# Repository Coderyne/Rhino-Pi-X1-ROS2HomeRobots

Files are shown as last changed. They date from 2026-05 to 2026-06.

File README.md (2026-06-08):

<div align="center">

# 基于犀牛派X1的家庭机器人







基于犀牛派X1的家庭机器人，集成了视觉、语音、运动控制、SLAM导航和智能家居联动等多种功能，能够实现智能交互和自主导航。

</div>

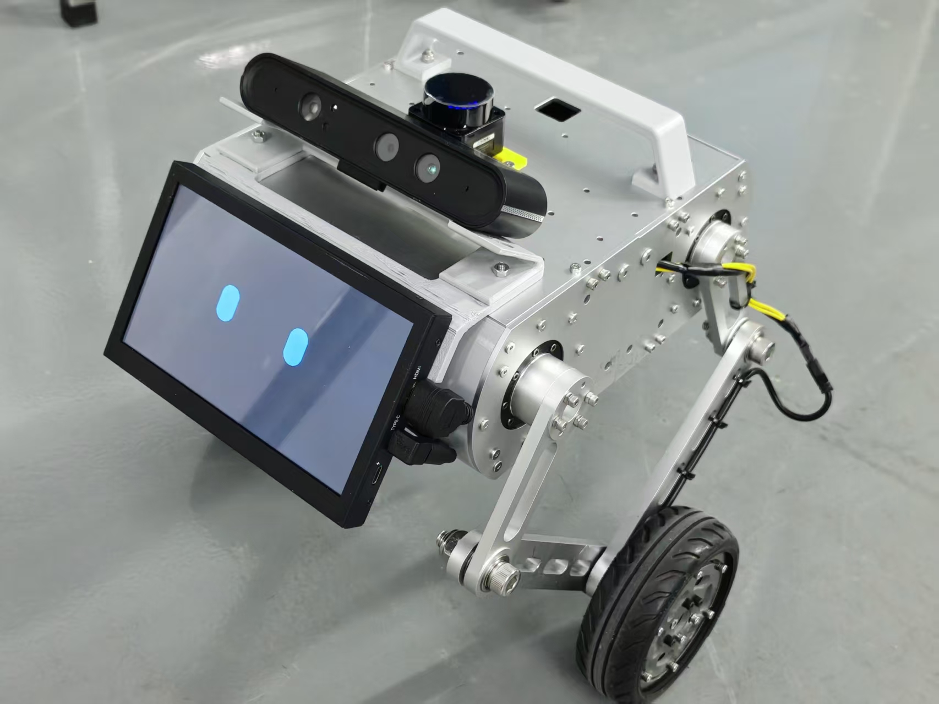
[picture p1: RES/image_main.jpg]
机器人实物图


---

## 目录

- [功能概览](#功能概览)
- [硬件规格](#硬件规格)
- [软件架构](#软件架构)
- [文件结构](#文件结构)
- [安装教程](#安装教程)
- [参考](#参考)
---

## 功能概览

- **轮足机器人控制** — 基于 STM32H723 + FreeRTOS 的底层控制，集成 EKF/Mahony 姿态解算、LQR 平衡控制、VMC 腿部运动学，支持前进/转向/跳跃/自起等动作能力。兼容 Xbox 无线手柄遥控，通过串口协议接收 ROS2 上位机指令。
- **SLAM/导航** — 集成 slam_toolbox 建图和 Nav2 导航框架，支持 AMCL 全局定位、路径规划与动态避障。提供区域导航管理（命名区域 + JSON 持久化），支持 Web 仪表盘可视化交互。
- **人员跟随** — 基于人工势场法的人体跟随，支持 Web 端框选目标，自动发布 `/goal_pose` 驱动机器人跟随。
- **ASR/TTS/KWS** — 本地部署 sherpa-onnx 关键词唤醒 + AidVoice NPU SenseVoice 语音识别 + VITS-Piper 中文语音合成，实现完全离线的语音交互。
- **GIF 表情播放器** — 基于 PySide6 的全屏 GIF 播放器，通过命名管道动态切换，实现情感化交互反馈。
- **Qwen3-4B LLM** — 在 NPU 上本地部署 Qwen3-4B-Instruct 模型，支持流式对话推理，通过 OpenAI 协议对接 Home Assistant 的语音Agent。
- **Home Assistant 集成** — 通过 MQTT 桥接和 REST API 将机器人传感器、状态、控制指令集成到 Home Assistant，实现智能家居联动和语音控制。
- **Web 仪表盘** — 基于 roslibjs 的实时 Web 可视化面板，支持实时数值/曲线监控、交互式地图（缩放/平移/导航选点/区域管理）、控制面板（运动控制/使能/急停）。

---

## 硬件规格

| 类别 | 组件 | 说明 |
|---|---|---|
| 上位机主控 | X1 派 (Rhino Pi X1) | 运行 Ubuntu + ROS2 + 本地 AI 模型 |
| 下位机主控 | 达妙 DM-MC02(STM32H723VGT6) | 电机驱动与控制 |
| Xbox手柄通信(可选) | ESP32 | BLE 连接 Xbox 手柄，串口转发至 STM32 |
| 关节电机 | GIM6010 ×4 | CAN 总线，髋关节驱动 |
| 轮毂电机 | DM6215 ×2 | CAN 总线，驱动轮 |
| IMU | BMI088 | 板载传感器，支持6轴姿态检测 |
| 激光雷达 | LD06 | 360° 2D 激光雷达 |
| 深度相机 | 奥比中光AstraPro | 视觉感知 |
| 显示屏 | 7 寸HDMI触摸屏 | 表情显示&触摸交互 |
| 电池 | DJI Matrice 4D电池 | 机器人24V供电 |

---

## 软件架构

```
┌───────────────────────────────────────────────────────────────┐
│                      智能家居层                                │
│   Home Assistant (Docker)                                     │
│   Assist Pipeline (STT → Conversation Agent → TTS)            │
│   MQTT Broker                                                 │
└─────┬──────────────────────────┬──────────────────────────────┘
      │ REST / Wyoming           │ MQTT
      ▼                          ▼
┌───────────────────────────────────────────────────────────────┐
│                      X1-Pi (ROS2 Humble)                       │
│                                                               │
│  ┌──────────────┐  ┌──────────────┐  ┌────────────────────┐   │
│  │ HA_Voice     │  │ Qwen3-4B LLM │  │ emotion_display    │   │
│  │ Assistant    │  │ (NPU 推理)    │  │ (GIF 表情播放)     │   │
│  │ (KWS/ASR/TTS)│  └──────┬───────┘  └────────────────────┘   │
│  └──────┬───────┘         │                                   │
│         │                 │                                   │
│  ┌──────┴─────────────────┴──────────────────────────────┐    │
│  │              ROS2 功能包 (wheel_legged_-ros2)          │   │
│  │                                                        │   │
│  │  stm32_bridge  wheel_foot_nav  perception              │   │
│  │  mqtt_bridge   region_manager  ldlidar_driver          │   │
│  │                                                        │   │
│  │  rosbridge_websocket ──► Web 仪表盘 (:8192)            │   │
│  └──────────────────────┬─────────────────────────────────┘   │
└─────────────────────────┼─────────────────────────────────────┘
                          │ UART (USB CDC)
                          ▼
┌───────────────────────────────────────────────────────────────┐
│                  STM32H723 (FreeRTOS)                         │
│                                                               │
│  姿态解算 (EKF/Mahony)  VMC 腿部控制  PID 控制器                │
│  LQR 平衡控制          跳跃控制       自起控制                  │
│  DM4310 / GIM6010 电机驱动 (CAN)                               │
│  Xbox 遥控接收   VOFA+ 调试输出  电源管理                       │
└─────┬─────────────────────────────────────────────────────────┘
      │ UART(可选)
      ▼
┌───────────────────────────────────────────────────────────────┐
│                     ESP32 (Xbox BLE)                          │
│  Xbox Series X 手柄蓝牙连接 → HID 解析 → 串口转发至 STM32       │
└───────────────────────────────────────────────────────────────┘
```

---

## 文件结构

整个机器人项目分为以下几个部分，分别位于仓库不同目录下，内部有更详细的说明：

- **[`Guide`](Guide)** — 项目文档与指南
  - [`机器人硬件安装指南.pdf`](Guide/机器人硬件安装指南.pdf) — 机械组装步骤
  - [`物料清单-机械.xlsx`](Guide/物料清单-机械.xlsx) / [`物料清单-电子.xlsx`](Guide/物料清单-电子.xlsx) — 完整 BOM
  - `Guide/STM32/` — [固件烧录教程](Guide/STM32/DM-MC02固件烧录教程.pdf) + 预编译固件 (.hex)
  - `Guide/X1_Ubuntu/` — X1 派部署指南：[Home Assistant](Guide/X1_Ubuntu/HomeAssistant/HomeAssistant-Docker安装.md) / [Qwen3-4B](Guide/X1_Ubuntu/Qwen3-4B-Instruct部署/Qwen3-4B-Instruct部署.md) / [语音助手](Guide/X1_Ubuntu/VoiceAssistant/语音助手部署指南.md) / [开机自启](Guide/X1_Ubuntu/开机自启配置.md)
  - 各电机/外设使用手册（LD06 雷达、GIM6010 电机、DM-MC02 开发板等）

- **[`Machine`](Machine)** — 机械结构设计与加工文件
  - [`3D打印件/`](Machine/3D打印件/) — 前/后面板、握把、支架等 3D 打印件
  - [`机加工件/`](Machine/机加工件/) — CNC 铝合金件 (底板/顶板/侧板/腿) + 玻纤板
  - [`SolidWorks/`](Machine/SolidWorks/) — SolidWorks 装配体 (`总装.SLDASM`) + 全部零件

- **[`Code`](Code)** — 软件代码（核心部分），详见 [Code/README.md](Code/README.md)
  - [`ESP32/ESP32_connect_Xbox/`](Code/ESP32/ESP32_connect_Xbox/) — [PlatformIO 工程](Code/ESP32/ESP32_connect_Xbox/README.md)，Xbox 手柄 BLE 桥接 → 串口转发（[串口协议](Code/ESP32/ESP32_connect_Xbox/SERIAL_PROTOCOL.md)）
  - [`STM32/ros2-wheel-foot-car/`](Code/STM32/ros2-wheel-foot-car/) — [Keil MDK 工程](Code/STM32/ros2-wheel-foot-car/README.md)，底层运动控制固件（EKF/VMC/PID/ROS2 通信）
  - [`X1-Pi/`](Code/X1-Pi/) — X1 派应用层
    - [`ROS2_Packages/`](Code/X1-Pi/ROS2_Packages/wheel_legged_-ros2/) — [ROS2 工作空间](Code/X1-Pi/ROS2_Packages/wheel_legged_-ros2/README.md)（stm32_bridge / Nav2 / perception / mqtt_bridge / region_manager / Web 仪表盘 / LiDAR 驱动）
    - [`HA_VoiceAssistant/`](Code/X1-Pi/HA_VoiceAssistant/) — [语音助手](Code/X1-Pi/HA_VoiceAssistant/README.md)（KWS + ASR + TTS + HA 集成）
    - [`emotion_display/`](Code/X1-Pi/emotion_display/) — [GIF 表情播放器](Code/X1-Pi/emotion_display/README.md)
    - [`Aid_LLM/`](Code/X1-Pi/Aid_LLM/) — Qwen3-4B-Instruct 本地部署

- **[`PCB`](PCB)** — 电路设计文件
  - [`分电板/`](PCB/分电板/) — 电源分配板 Gerber 文件 + BOM
  - [`降压板/`](PCB/降压板/) — 24V 降压板 Gerber 文件 + BOM

- **[`Matlab`](Matlab)** — [算法仿真](Matlab/simulation/README.md)
  - Simulink 轮腿动力学模型 + LQR 控制器设计

- **[`RES`](RES)** — 项目资源文件

---

## 安装教程

### 硬件部分

1. 参阅 [Machine/README.md](Machine/README.md) ，对 `3D打印件/` 和 `机加工件/` 目录下的设计文件进行加工
2. 参考 [物料清单-机械.xlsx](Guide/物料清单-机械.xlsx) 和 [物料清单-电子.xlsx](Guide/物料清单-电子.xlsx) 采购所需零件
3. 参阅 [PCB/](PCB/) 目录打样分电板和降压板
4. 参考 [Guide/机器人硬件安装指南.pdf](Guide/机器人硬件安装指南.pdf) 进行机械组装

### 软件部分

**系统要求：**
- X1 派：Ubuntu 22.04

**部署步骤：**

依次对 `Code/` 目录下的各子系统进行编译和部署：

| 子系统 | 文档入口 | 说明 |
|---|---|---|
| ESP32 | [README.md](Code/ESP32/ESP32_connect_Xbox/README.md) | PlatformIO 编译烧录 |
| STM32 | [README.md](Code/STM32/ros2-wheel-foot-car/README.md) | Keil MDK 编译下载，烧录教程见 [Guide/STM32/](Guide/STM32/) |
| ROS2 包 | [README.md](Code/X1-Pi/ROS2_Packages/wheel_legged_-ros2/README.md) | colcon 编译 + 一键启动脚本 |
| 语音助手 | [README.md](Code/X1-Pi/HA_VoiceAssistant/README.md) | Python 依赖安装 + 模型配置 |
| LLM 部署 | [部署指南](Guide/X1_Ubuntu/Qwen3-4B-Instruct部署/Qwen3-4B-Instruct部署.md) | NPU 模型推理部署 |
| Home Assistant | [部署指南](Guide/X1_Ubuntu/HomeAssistant/HomeAssistant-Docker安装.md) | Docker 安装 + 集成配置 |
| 开机自启 | [配置指南](Guide/X1_Ubuntu/开机自启配置.md) | systemd 服务配置 |

> **🚧 TODO：** X1 派的部署步骤较为复杂，后续将打包上传完整镜像文件至网盘，以便一键烧录部署。

---

## 参考

- [《轮腿式平衡机器人控制》— 陈阳](Matlab/simulation/轮腿式平衡机器人控制_陈阳.pdf)
- [达妙开源轮腿机器人项目](https://gitee.com/kit-miao/wheel-legged)
- [sherpa-onnx](https://github.com/k2-fsa/sherpa-onnx)
- [Home Assistant](https://www.home-assistant.io/)
- [ROS2](https://docs.ros.org/en/humble/) 
- [Qwen3](https://github.com/QwenLM/Qwen3)
- [VITS-Piper](https://github.com/rhasspy/piper)

---

本项目基于 Apache License 2.0 开源。详见 [LICENSE](LICENSE)。

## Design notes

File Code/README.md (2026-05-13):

## 文件结构

以下是上位机和下位机的代码, 是项目的核心部分:

- [`ESP32`](ESP32)：用于通过蓝牙连接Xbox手柄，再通过串口与STM32通信，方便在调试时直接控制机器人
- [`STM32`](STM32)：用于控制机器人的底盘控制，通过LQR+VMC控制维持机器人平衡
- [`X1-Pi`](X1-Pi)：X1派应用层代码，负责跑ROS2，本地模型。实现人机交互等功能

---

### 待补充...

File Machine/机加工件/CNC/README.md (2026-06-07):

# CNC 加工件

机器人结构件的 CNC 加工文件，可直接用于 CNC 加工。

## 加工清单

| 零件名称 | 数量 | 文件名 |
| --- | :--: | --- |
| 底板 | 1 | `底板.STEP` |
| 顶板 | 1 | `顶板.STEP` |
| 左侧板 | 2 | `左侧板.STEP` |
| 右侧板 | 2 | `右侧板.STEP` |
| 上腿 | 4 | `上腿.STEP` |
| 下腿 A | 2 | `下腿A.STEP` |
| 下腿 B | 2 | `下腿B.STEP` |
| 4.5mm 垫高片 | 2 | `4.5mm垫高片.STEP` |
| 15mm 垫高片 | 2 | `15mm垫高片.STEP` |
| 大疆电池转接架 | 1 | `大疆电池转接架.STEP` |

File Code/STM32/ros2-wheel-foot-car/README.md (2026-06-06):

# ros2-wheel-foot-car

基于 **STM32H723** + **FreeRTOS** 的轮足机器人底层控制固件，包含姿态解算、VMC 腿部控制、CAN 电机驱动、遥控输入（PS2/Xbox）、ROS2 通信等核心模块，实现轮足底盘的平衡、运动与跳跃控制。

## 硬件平台

| 组件 | 型号 |
|---|---|
| MCU | STM32H723VGT6 (Cortex-M7, 550MHz) |
| IMU | BMI088 (SPI) |
| 关节电机 | DM4310 × 2 (CAN) |
| 轮毂电机 | GIM6010 × 2 (CAN) |
| 遥控 | PS2 无线手柄 / Xbox 无线手柄 |
| 调试输出 | USART1 → VOFA+ |
| 上位机通信 | USART → ROS2 (串口协议) |

## 目录结构

```
ros2-wheel-foot-car/
├── Core/                      # CubeMX 生成代码 (HAL / FreeRTOS / 启动)
│   ├── Inc/                   #   头文件 (FreeRTOSConfig, main, stm32h7xx_it 等)
│   └── Src/                   #   源文件 (main, freertos, 中断服务)
├── Drivers/                   # CMSIS + STM32H7 HAL 驱动
├── Middlewares/               # 中间件 (ST / Third_Party)
├── USB_DEVICE/                # USB 设备栈 (App / Target)
├── User/                      # 🔑 核心业务代码
│   ├── APP/                   # 任务层 (FreeRTOS 任务入口)
│   │   ├── INS_task.c/h       #   姿态估计任务 (IMU 数据融合)
│   │   ├── chassisL_task.c/h  #   左腿底盘控制任务
│   │   ├── chassisR_task.c/h  #   右腿底盘控制任务
│   │   ├── observe_task.c/h   #   观测/监控任务
│   │   ├── ps2_task.c/h       #   PS2 手柄控制任务
│   │   ├── xbox_task.c/h      #   Xbox 手柄控制任务
│   │   ├── Power/             #   电源管理 (ADC 电压检测 / 蜂鸣器告警)
│   │   ├── ROS/               #   ROS2 通信任务 (串口协议收发)
│   │   └── Vofa/              #   VOFA+ 调试输出 (浮点流可视化)
│   ├── Algorithm/             # 算法层
│   │   ├── EKF/               #   四元数扩展卡尔曼滤波 (QuaternionEKF)
│   │   ├── PID/               #   PID 控制器
│   │   ├── VMC/               #   虚拟模型控制 (VMC 腿部运动学/动力学)
│   │   ├── kalman/            #   卡尔曼滤波器
│   │   └── mahony/            #   Mahony AHRS + 互补滤波
│   ├── Devices/               # 设备驱动
│   │   ├── BMI088/            #   BMI088 IMU 驱动 + 中间件 (SPI)
│   │   ├── DM_Motor/          #   DM4310 关节电机驱动 (CAN)
│   │   └── SW_Motor/          #   GIM6010 轮毂电机驱动 (CAN)
│   ├── Controller/            # 顶层控制器 (controller.c/h)
│   ├── Bsp/                   # 板级支持包 (PWM / DWT 定时 / CAN)
│   └── Lib/                   # 用户工具库 (user_lib)
├── MDK-ARM/                   # Keil MDK 工程
│   ├── CtrlBoard-H7_IMU.uvprojx   # 主工程文件
│   └── startup_stm32h723xx.s      # 启动汇编
├── build/                     # 编译输出
├── CtrlBoard-H7_IMU.ioc       # CubeMX 硬件配置
├── 通信协议-STM32与ROS2.md     # STM32 ↔ ROS2 串口通信协议
└── Xbox键位.md                # Xbox 手柄键位与控制映射
```

## 控制架构

```
┌─────────────────────────────────────────────────────┐
│                    传感器层                           │
│   BMI088 IMU ──► SPI ──► 姿态解算 (EKF/Mahony)       │
│   电机编码器 ◄──► CAN ──► 速度/位置反馈               │
└──────────────────────┬──────────────────────────────┘
                       ▼
┌─────────────────────────────────────────────────────┐
│                    算法层                             │
│   Kalman 滤波 → QuaternionEKF → Mahony AHRS          │
│   PID 控制器 → VMC 腿部运动学/动力学计算              │
└──────────────────────┬──────────────────────────────┘
                       ▼
┌─────────────────────────────────────────────────────┐
│                    控制层                             │
│   controller.c  ──  平衡 / 速度 / 位置 / 转向 / 跳跃  │
│   chassisL/R  ──  左右腿独立控制 (离地检测 / 相位)    │
└──────────────────────┬──────────────────────────────┘
                       ▼
┌─────────────────────────────────────────────────────┐
│                    执行层                             │
│   DM4310 关节电机 (CAN)  │  GIM6010 轮毂电机 (CAN)   │
└─────────────────────────────────────────────────────┘
```

## 任务系统 (FreeRTOS)

| 任务 | 文件 | 周期 | 功能 |
|---|---|---|---|
| INS | `INS_task.c` | ~1ms | IMU 数据读取 + 姿态融合 |
| ChassisL | `chassisL_task.c` | ~1ms | 左腿 VMC 计算 + 电机控制 |
| ChassisR | `chassisR_task.c` | ~1ms | 右腿 VMC 计算 + 电机控制 |
| Observe | `observe_task.c` | — | 状态监控 |
| PS2 | `ps2_task.c` | — | PS2 手柄数据接收与解析 |
| Xbox | `xbox_task.c` | ~55ms | Xbox 手柄数据接收与解析 |
| ROS2 | `ROS/ros2_task.c` | — | 串口协议收发 (上位机通信) |
| Power | `Power/power_task.c` | 2s | 电池电压检测 / 低压蜂鸣器告警 |
| Vofa | `Vofa/vofa_task.c` | 100ms | 调试数据发送 (USART1) |

## 遥控输入

支持双遥控方案，详见：

- **PS2 手柄**：[`User/APP/ps2_task.c`](User/APP/ps2_task.c) — 无线接收器接入，解析按键 + 摇杆数据
- **Xbox 手柄**：[`User/APP/xbox_task.c`](User/APP/xbox_task.c) — 键位与控制映射见 [`Xbox键位.md`](Xbox键位.md)

### Xbox 控制摘要

| 输入 | 功能 |
|---|---|
| A 键 (上升沿) | 底盘启停切换 |
| LB + RB (同时按下) | 触发跳跃 |
| B 键 (电平) | 横滚复位 |
| 左摇杆 Y/X | 前后速度 / 转向 |
| 右摇杆 X/Y | 横滚 / 腿长 |

## 构建与下载

### Keil MDK-ARM (推荐)

1. 打开 `MDK-ARM/CtrlBoard-H7_IMU.uvprojx`
2. 选择目标 `CtrlBoard-H7_IMU`
3. 编译 (F7) → 下载 (F8)

### CubeMX 配置

硬件配置工程 `CtrlBoard-H7_IMU.ioc`，可在 STM32CubeMX 中打开修改引脚/外设配置，重新生成 `Core/` 代码。

## 调试

### VOFA+ 实时波形

通过 USART1 发送浮点数据到 [VOFA+](https://www.vofa-plus.com/) 进行可视化调试：

- 帧格式：float 数组 + `00 00 80 7F` 帧尾 (JustFloat)
- 当前发送 9 路数据，替换 `data[]` 为实际调试变量即可

> 详见 [`User/APP/Vofa/README.md`](User/APP/Vofa/README.md)

### 电源管理

- 三路电源输出控制 (DC24_0 / DC24_1 / DC5)
- 电池电压 ADC 采样，低压 (<24V) 蜂鸣器告警

> 详见 [`User/APP/Power/README.md`](User/APP/Power/README.md)

## 相关文档

| 文档 | 说明 |
|---|---|
| [`通信协议-STM32与ROS2.md`](通信协议-STM32与ROS2.md) | STM32 ↔ ROS2 串口通信协议定义 |
| [`Xbox键位.md`](Xbox键位.md) | Xbox 手柄键位与控制映射 |
| [`User/APP/Power/README.md`](User/APP/Power/README.md) | 电源管理模块说明 |
| [`User/APP/Vofa/README.md`](User/APP/Vofa/README.md) | VOFA+ 调试模块说明 |

## 开发须知

- 阅读代码入口建议从 `Core/Src/main.c` 的任务创建开始，再到 `User/APP/` 各任务文件
- 修改遥控映射或控制参数后，请同步更新对应说明文档 ([`Xbox键位.md`](Xbox键位.md)、[`通信协议-STM32与ROS2.md`](通信协议-STM32与ROS2.md))
- `Core/` 由 CubeMX 生成，手动修改可能被覆盖；业务逻辑请写在 `User/` 下
- 代码格式化使用 `.clang-format`，支持 VS Code 和 Keil

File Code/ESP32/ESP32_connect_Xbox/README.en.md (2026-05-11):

# Xbox Series X Controller ESP32 Example

This project, built on the PlatformIO platform, enables BLE communication between an ESP32-C3 and an Xbox Series X controller.

## Project Overview

This project facilitates Bluetooth communication between an ESP32-C3 development board and an Xbox Series X / Xbox One controller. It parses input data such as buttons, joysticks, and triggers, outputs formatted data via serial, and supports vibration feedback.

## Hardware Requirements

- ESP32-C3 development board (default config: [weactstudio_esp32c3coreboard](https://github.com/WeActStudio/WeActStudio.ESP32C3CoreBoard))
- Xbox Series X / Xbox One controller (must support Bluetooth)

## Software Dependencies

- [PlatformIO](https://platformio.org/)
- Arduino framework
- [NimBLE-Arduino](https://github.com/h2zero/NimBLE-Arduino) (BLE stack)

## Project Structure

```
├── platformio.ini                               # PlatformIO configuration
├── src/
│   ├── main.cpp                                 # Main program entry
│   ├── XboxControllerNotificationParser.h       # Notification data parser
│   ├── XboxControllerNotificationParser.cpp     # Parser implementation
│   ├── XboxSeriesXControllerESP32_asukiaaa.hpp  # Controller BLE driver
│   └── XboxSeriesXHIDReportBuilder_asukiaaa.hpp  # HID vibration report builder
└── README.md
```

## Features

- Parse all button inputs (Y/X/B/A/LB/RB/Select/Start/Xbox/Share/LS/RS/D-pad)
- Read dual joystick analog values (normalized to -100~100)
- Read dual trigger values (normalized to 0~100)
- Four vibration feedback modes (left/right/center/shake) with adjustable power, duration, and repeat count
- Custom 11-byte binary protocol over Serial1 (GPIO 20/21) with header and checksum
- Auto-trigger 250ms vibration when receiving a `0x07 0x21` header frame on Serial1 (with 300ms debounce cooldown)
- Auto-reconnect on BLE disconnect; auto-restart after 2 failed connection attempts

## Usage

### 1. Configure Controller MAC Address

Edit `src/main.cpp` line 7, replacing with your controller's Bluetooth MAC address:

```cpp
XboxSeriesXControllerESP32_asukiaaa::Core
    xboxController("58:d0:05:0e:85:8d"); // Replace with your controller's address
```

> **Finding your controller's MAC address**: Windows Settings → Bluetooth & devices → Devices → Xbox Wireless Controller → Properties. Or check the serial log after scanning.

### 2. Compile and Upload

```bash
# Compile the project
pio run

# Upload to ESP32-C3
pio run --target upload

# Monitor serial output
pio device monitor
```

> PlatformIO installs dependencies automatically based on `platformio.ini`. No manual installation needed.

For other ESP32 boards, modify the `board` setting in `platformio.ini`.

### 3. Serial Monitor

After connecting the ESP32, the serial output will show connection status. Once connected, 11-byte binary data frames are continuously output via Serial1 (GPIO 20/21, 115200).

## Serial Data Protocol

After connection, an 11-byte binary frame is sent every 10ms via Serial1:

| Byte | Content |
|---|---|
| 0-1 | Header `0x07 0x21` |
| 2 | Left joystick X (-100~100 mapped to 28~228) |
| 3 | Left joystick Y (-100~100 mapped to 28~228) |
| 4 | Right joystick X (-100~100 mapped to 28~228) |
| 5 | Right joystick Y (-100~100 mapped to 28~228) |
| 6 | Left trigger LT (0~100) |
| 7 | Right trigger RT (0~100) |
| 8 | Button group 1 (bit0:A, bit1:LB, bit2:RB, bit3:Xbox) |
| 9 | Button group 2 (bit0:B, bit1:X, bit2:Y) |
| 10 | Checksum (lower 8 bits of sum of first 10 bytes) |

## Vibration Control

Four vibration modes, freely combinable:

| Mode | Description |
|---|---|
| `left` | Upper-left motor |
| `right` | Upper-right motor |
| `center` | Lower dual motors, high frequency, low power |
| `shake` | Lower dual motors, low frequency, high power |

### Auto Vibration

When Serial1 receives a frame with header `0x07 0x21`, the controller automatically triggers a 250ms vibration (shake + center mode, 50% power) with a 300ms debounce cooldown. Useful for haptic feedback notifications from a remote device.

## Notes

1. You must set your controller's Bluetooth MAC address in the code before use
2. The controller must be in pairing mode (hold the pairing button on top, Xbox light flashes rapidly)
3. When using other ESP32 boards, adjust `board` and serial pin settings in `platformio.ini`
4. Lower-left and lower-right motors are bound together and can only operate simultaneously

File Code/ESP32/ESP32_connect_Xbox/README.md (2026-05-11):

# Xbox Series X Controller ESP32 示例

本项目基于 PlatformIO 平台，通过蓝牙 BLE 实现 ESP32-C3 与 Xbox Series X 手柄的通信交互。

## 项目简介

该项目用于 ESP32-C3 开发板与 Xbox Series X / Xbox One 手柄之间的蓝牙通信，可解析手柄的按键、摇杆、扳机等输入数据，通过串口输出，并支持振动反馈功能。

## 硬件要求

- ESP32-C3 开发板（默认配置 [weactstudio_esp32c3coreboard](https://github.com/WeActStudio/WeActStudio.ESP32C3CoreBoard)）
- Xbox Series X / Xbox One 手柄（支持蓝牙的型号）

## 软件依赖

- [PlatformIO](https://platformio.org/)
- Arduino 框架
- [NimBLE-Arduino](https://github.com/h2zero/NimBLE-Arduino)（蓝牙 BLE 协议栈）

## 项目结构

```
├── platformio.ini                               # PlatformIO 配置文件
├── src/
│   ├── main.cpp                                 # 主程序入口
│   ├── XboxControllerNotificationParser.h       # 手柄通知数据解析器
│   ├── XboxControllerNotificationParser.cpp     # 解析器实现
│   ├── XboxSeriesXControllerESP32_asukiaaa.hpp  # 手柄 BLE 驱动
│   └── XboxSeriesXHIDReportBuilder_asukiaaa.hpp  # HID 振动报告构建器
└── README.md
```

## 功能特性

- 解析 Xbox Series X 手柄的全部按键输入（Y/X/B/A/LB/RB/Select/Start/Xbox/Share/LS/RS/十字键）
- 读取双摇杆模拟值（归一化到 -100~100）
- 读取双扳机键程值（归一化到 0~100）
- 支持四种振动反馈模式（左/右/高频/低频），可调力度、时长和循环次数
- 自定义 11 字节二进制串口协议输出（通过 Serial1，GPIO 20/21），含包头和校验和
- Serial1 接收包头 `0x07 0x21` 的帧时自动触发 250ms 振动（带 300ms 防抖冷却）
- 蓝牙断连后自动重连，连接失败超 2 次自动重启

## 使用方法

### 1. 配置手柄 MAC 地址

编辑 `src/main.cpp` 第 7 行，替换为自己的手柄蓝牙 MAC 地址：

```cpp
XboxSeriesXControllerESP32_asukiaaa::Core
    xboxController("58:d0:05:0e:85:8d"); // 替换为你的手柄地址
```

> **获取手柄 MAC 地址的方法**：Windows 设置 → 蓝牙和其他设备 → 设备 → Xbox Wireless Controller → 属性。或连接后查看串口日志。

### 2. 编译上传

```bash
# 编译项目
pio run

# 上传到 ESP32-C3
pio run --target upload

# 查看串口输出
pio device monitor
```

> PlatformIO 会根据 `platformio.ini` 自动安装依赖，无需手动安装。

如果使用其他 ESP32 板子，请修改 `platformio.ini` 中的 `board` 配置。

### 3. 串口监视器

连接 ESP32 后，串口将输出手柄连接状态。连接成功后，通过 `Serial1` (GPIO 20/21, 115200) 持续输出 11 字节的二进制数据帧。

## 串口数据协议

连接成功后，每 10ms 通过 Serial1 输出一帧 11 字节的二进制数据：

| 字节 | 内容 |
|---|---|
| 0-1 | 包头 `0x07 0x21` |
| 2 | 左摇杆 X（-100~100 映射到 28~228） |
| 3 | 左摇杆 Y（-100~100 映射到 28~228） |
| 4 | 右摇杆 X（-100~100 映射到 28~228） |
| 5 | 右摇杆 Y（-100~100 映射到 28~228） |
| 6 | 左扳机 LT（0~100） |
| 7 | 右扳机 RT（0~100） |
| 8 | 按钮组 1（bit0:A, bit1:LB, bit2:RB, bit3:Xbox） |
| 9 | 按钮组 2（bit0:B, bit1:X, bit2:Y） |
| 10 | 校验和（前 10 字节求和取低 8 位） |

## 振动控制

支持四种振动模式，可随意搭配：

| 模式 | 说明 |
|---|---|
| `left` | 上左电机 |
| `right` | 上右电机 |
| `center` | 下双电机高频低力量 |
| `shake` | 下双电机低频大力量 |

### 自动振动

当 Serial1 接收到包头 `0x07 0x21` 的完整帧时，手柄自动触发 250ms 振动（shake + center 模式，50% 力度），带 300ms 冷却防抖。可用于对端设备的力反馈通知。

## 注意事项

1. 使用前必须在代码中填入自己手柄的蓝牙 MAC 地址
2. 手柄需要处于配对模式（长按手柄顶部配对按钮，Xbox 灯快闪）
3. 使用其他 ESP32 板子时需调整 `platformio.ini` 中的 `board` 和串口引脚配置
4. 下左电机和下右电机是绑定的，只能同时动作

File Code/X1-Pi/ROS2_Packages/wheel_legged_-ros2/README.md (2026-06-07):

# Wheel Legged Robot — ROS2 开发工作空间

> 轮足机器人上位机 ROS2 Humble 开发工作空间，支持底盘通讯、Web 可视化、激光 SLAM 建图、自主导航、区域导航、MQTT 桥接。

## 项目结构

```
wheel_legged_-ros2/
├── src/
│   ├── stm32_bridge/              # STM32 USB CDC 通讯桥接包
│   │   ├── stm32_bridge/
│   │   │   ├── protocol.py        # CRC16 / 帧打包解包 / 逐字节状态机解析
│   │   │   └── wheel_foot_bridge.py  # 主节点 (遥测/指令/TF广播)
│   │   ├── launch/
│   │   ├── config/
│   │   └── README.md
│   ├── wheel_foot_nav/            # SLAM & Nav2 导航包
│   │   ├── launch/
│   │   │   ├── slam.launch.py     # 建图 (slam_toolbox + RViz)
│   │   │   ├── nav.launch.py      # 导航 (map_server + AMCL + Nav2 + RViz + 人跟随)
│   │   │   └── bringup.launch.py  # 基础 bringup
│   │   ├── config/
│   │   │   ├── slam_toolbox.yaml  # SLAM 参数
│   │   │   └── nav2_params.yaml   # Nav2 全套参数
│   │   ├── rviz/
│   │   │   ├── slam.rviz          # 建图 RViz 配置 (自动加载)
│   │   │   └── nav.rviz           # 导航 RViz 配置 (自动加载)
│   │   ├── scripts/
│   │   │   └── lifecycle_boot.py  # map_server/AMCL 等 9 节点生命周期引导
│   │   └── maps/                  # 保存的地图文件
│   ├── perception/                 # 人体跟随 (LiDAR 质心漂移 + Kalman)
│   │   ├── perception/
│   │   │   └── person_follower.py # 跟随节点 (质心漂移 + Kalman + TF → /goal_pose)
│   │   ├── config/
│   │   │   └── params.yaml        # 跟随参数 (搜索半径/跟随距离/限流阈值)
│   │   └── launch/
│   │       └── person_follower.launch.py
│   ├── mqtt_bridge/               # MQTT ↔ ROS2 桥接包
│   │   ├── mqtt_bridge/
│   │   │   └── mqtt_node.py       # MQTT 协议转 ROS2 节点
│   │   ├── launch/
│   │   └── config/
│   └── region_manager/            # 区域导航管理
│       ├── region_manager/
│       │   ├── region_manager.py  # ROS2 节点 (Topic+Service, MarkerArray 可视化)
│       │   └── region_store.py    # JSON 文件持久化
│       ├── launch/
│       └── config/
├── ldlidar_ros2_ws/               # LD19/LD06 激光雷达工作空间
│   └── src/ldlidar_stl_ros2/
├── reloc                           # AMCL 全局重定位独立脚本
├── web/                           # Web 可视化仪表盘
│   ├── index.html                 # 实时数值/关节/控制 + 地图导航面板 + 跟随 + 区域管理
│   ├── css/dashboard.css
│   └── js/dashboard.js            # roslibjs 连接 + 地图渲染(缩放/平移) + 导航交互 + 跟随 + 区域划分
├── start.sh                       # 一键启动脚本
└── 通信协议-STM32与ROS2.md       # 下位机通讯协议参考
```

## 功能包

| 包名 | 工作空间 | 说明 |
|---|---|---|
| `stm32_bridge` | wheel_legged_-ros2 | STM32 USB CDC 通讯桥接（遥测/指令/TF广播） |
| `wheel_foot_nav` | wheel_legged_-ros2 | SLAM 建图 & Nav2 导航启动与配置 |
| `perception` | wheel_legged_-ros2 | LiDAR 人体跟随（质心漂移 + Kalman + Nav2 目标发布） |
| `mqtt_bridge` | wheel_legged_-ros2 | MQTT ↔ ROS2 双向桥接 (Web/MQTT 控制) |
| `region_manager` | wheel_legged_-ros2 | 地图区域划分、持久化存储、区域导航 (Topic + Service) |
| `ldlidar_stl_ros2` | ldlidar_ros2_ws | LD19/LD06 激光雷达驱动 |

## 依赖

```bash
# 系统包
sudo apt install ros-humble-rosbridge-suite \
               ros-humble-slam-toolbox \
               ros-humble-navigation2 \
               ros-humble-nav2-bringup \
               ros-humble-tf2-ros

# Python 包
pip3 install pyserial
```

## 编译

```bash
# 主工作空间
cd ~/ROS2_Dev/wheel_legged_-ros2          # 实际路径替换为你的工作空间
source /opt/ros/humble/setup.bash

# 全部编译
colcon build

# 或按需编译
colcon build --packages-select stm32_bridge wheel_foot_nav perception mqtt_bridge region_manager

source install/setup.bash

# 雷达驱动 (如未编译)
cd ~/ROS2_Dev/wheel_legged_-ros2/ldlidar_ros2_ws
colcon build
```

## TF 坐标树

```
map → odom → base_footprint → base_link → base_laser
 ↑      ↑         ↑              ↑            ↑
slam   bridge新增  bridge发布    静态         lidar驱动
```

- `odom → base_footprint` 由 `wheel_foot_bridge` 发布，通过积分 `vel_n` 和 `yaw` 获得
- `base_link → base_laser` 由 `ldlidar_stl_ros2` 静态广播
- `map → odom` 由 `slam_toolbox` / `AMCL` 动态修正

## Web 仪表盘功能

浏览器打开 `http://<IP地址>:8192`，通过 rosbridge WebSocket 连接机器人。

### 数据监控
| 区域 | 内容 |
|---|---|
| 实时数值 | Yaw / Roll / Pitch / 速度 / 电池 / 运行状态 |
| 时序曲线 | 速度曲线 (vel_n + 角速度) / 姿态曲线 (roll + pitch) |
| 关节状态 | 左/右腿摆角条、腿长条、轮力矩条 |
| 触地状态 | 左/右着地指示、跳跃阶段 |

### 地图与导航
| 功能 | 说明 |
|---|---|
| 实时地图 | 订阅 `/map`，Canvas 渲染 OccupancyGrid（未知/空闲/障碍） |
| 缩放/平移 | 鼠标滚轮缩放(以光标为中心) + 拖拽平移 + +/- 按钮 |
| 激光扫描叠加 | 订阅 `/scan`，绿色半透明点云 |
| 路径显示 | 订阅 `/plan`，蓝色折线显示 Nav2 规划路径 |
| 机器人位置 | 订阅 `/tf`，红色三角箭头标示 map→base_footprint |
| 导航目标 | 点击按钮 → 两阶段选点(位置+朝向) → 发布 `/goal_pose` |
| 初始位姿 | 点击按钮 → 两阶段选点(位置+朝向) → 发布 `/initialpose` |
| 人体跟随 | 点击按钮 → 矩形框选目标 → 发布 `/follow_target`，机器人自动跟随 |
| 全局重定位 | 点击按钮 → 调用 `/reinitialize_global_localization` 撒粒子收敛 |
| 保存地图 | 调用 `/map_saver/save_map` 服务 |
| 取消导航 | 发送零速 `cmd_vel` + 当前位置 goal 终止导航 |
| 区域管理 | 点击按钮 → 矩形框选区域 → 命名+选色 → 持久化保存 |
| 区域导航 | 点击地图上的区域矩形 → 自动发布 `/goal_pose` 导航到区域中心 |

### 控制面板
`/cmd_vel` 滑条、使能/停止/急停/跳跃/自起按钮、`/cmd_attitude` 腿长/姿态滑条

## 运行

### 一键启动

```bash
./start.sh              # 基础模式: rosbridge + 底盘桥接 + MQTT + 区域管理 + Web 仪表盘
./start.sh slam         # 建图模式: 基础 + 雷达 + slam_toolbox + RViz
./start.sh nav <地图>   # 导航模式: 基础 + 雷达 + Nav2 + 人跟随 + RViz
./start.sh reloc        # 触发 AMCL 全局重定位 (导航模式运行时)
./start.sh attach       # 启动并进入 tmux 查看日志
./start.sh stop         # 停止所有服务
```

启动后访问 `http://<IP地址>:8192` 打开仪表盘。自定义端口：

```bash
ROSBRIDGE_PORT=9092 WEB_PORT=9000 ./start.sh
```

### SLAM 建图流程

```bash
# 1. 启动建图
./start.sh slam

# 2. 遥控机器人移动覆盖环境
#    浏览器仪表盘可实时查看地图和扫描数据

# 3. 保存地图 (两种方式)
#    方式A: Web 仪表盘点击 "保存地图" 按钮
#    方式B: 命令行
ros2 run nav2_map_server map_saver_cli -f src/wheel_foot_nav/maps/map
```

### Nav2 导航流程

```bash
# 1. 启动导航 (RViz 自动加载 nav.rviz 配置, 人跟随节点自动启动)
./start.sh nav map

# 2. AMCL 启动后自动调用 /reinitialize_global_localization 全局重定位，
#    粒子全地图随机撒播，通过 /scan 扫描匹配自动收敛到正确位姿。

# 3. 设置导航目标:
#    - Web 仪表盘: 点击 "导航目标" → 两阶段选点(位置+朝向)
#    - Web 仪表盘: 点击地图上的彩色区域矩形 → 自动导航到区域中心
#    - RViz: 使用 Nav2 Goal 工具
#    - 机器人自动规划并执行, 地图面板实时显示路径和位置

# 4. 人体跟随:
#    - Web 仪表盘: 点击 "跟随" → 矩形框选目标区域 → 机器人自动跟随
#    - 点击 "取消" 停止跟随

# 5. 手动重定位 (机器人被搬动后):
./start.sh reloc
```

### 人体跟随参数

| 参数 | 默认值 | 说明 |
|---|---|---|
| `target_radius` | 0.3m | 目标搜索半径 (框选时由矩形动态覆盖) |
| `follow_distance` | 0.8m | 期望跟随距离 |
| `goal_min_distance` | 0.025m | 目标位移阈值 (低于此不发新goal) |
| `goal_min_interval` | 0.5s | 两次 goal 最小间隔 |
| `enable_kalman` | true | Kalman 滤波平滑 |

配置文件: `src/perception/config/params.yaml`

### 区域导航

`region_manager` 将地图划分为可命名的矩形区域，支持 Web 端交互和外部程序调用。

#### 区域管理

1. **创建区域** — Web 仪表盘点击 "区域管理" → 地图上矩形框选 → 输入名称和颜色
2. **导航到区域** — 直接点击地图上的彩色区域矩形，机器人自动规划到区域中心点
3. **侧边栏管理** — 区域列表显示所有已划分区域，支持点击导航和删除

#### 接口

```bash
# 命令行导航到区域
ros2 topic pub /region_manager/navigate std_msgs/String \
    "data: '{\"name\":\"客厅\"}'" --once

# 列出所有区域
ros2 service call /region_manager/list_regions std_srvs/srv/Trigger

# 保存区域
ros2 topic pub /region_manager/save std_msgs/String \
    "data: '{\"name\":\"客厅\",\"x1\":-2.5,\"y1\":1.0,\"x2\":-0.5,\"y2\":3.0,\"color\":\"#FF6B6B\"}'" --once

# 删除区域
ros2 topic pub /region_manager/delete std_msgs/String \
    "data: '{\"name\":\"客厅\"}'" --once
```

#### Python 调用

```python
import json
from std_msgs.msg import String

# 导航到区域
pub = node.create_publisher(String, '/region_manager/navigate', 10)
pub.publish(String(data=json.dumps({"name": "客厅"})))

# LLM 集成示例: "去客厅" → 解析 → 区域导航
```

#### 参数

| 参数 | 默认值 | 说明 |
|---|---|---|
| `regions_file` | `~/robot_regions.json` | 区域数据持久化文件路径 |
| `map_frame` | `map` | 地图坐标系 |

配置文件: `src/region_manager/config/params.yaml`

区域数据存储在 JSON 文件中，格式如下：

```json
{
  "regions": [
    {
      "name": "客厅",
      "x1": -2.5, "y1": 1.0,
      "x2": -0.5, "y2": 3.0,
      "center_x": -1.5, "center_y": 2.0,
      "color": "#FF6B6B"
    }
  ]
}
```

### 手动启动

```bash
# 终端 1: rosbridge
ros2 launch rosbridge_server rosbridge_websocket_launch.xml port:=9091

# 终端 2: 底盘桥接
ros2 launch stm32_bridge bridge.launch.py

# 终端 3: Web 仪表盘
python3 -m http.server 8192 --directory web

# 终端 4: 雷达
ros2 launch ldlidar_stl_ros2 ld19.launch.py

# 终端 5: SLAM 建图
ros2 launch wheel_foot_nav slam.launch.py

# 终端 6: 区域管理 (可选)
ros2 launch region_manager region_manager.launch.py
```

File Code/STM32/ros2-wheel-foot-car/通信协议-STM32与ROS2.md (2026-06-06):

# 轮足机器人 STM32–ROS2 通信协议

> 下位机：STM32H723VGT6 + FreeRTOS + USB CDC (VCP)  
> 物理层：USB OTG HS Full-Speed (12 Mbps), 虚拟串口 `/dev/ttyACM0`  
> 遥测频率：100 Hz  
> 指令频率：上限 100 Hz（建议 ≥50 Hz 以维持使能状态）

---

## 一、帧格式（统一格式）

```
┌──────────┬──────────┬────────┬────────┬──────────────────┬──────────┐
│ Header0  │ Header1  │ Type   │ Len    │ Payload          │ CRC16    │
│ 0xAA     │ 0x55     │ 1 byte │ 1 byte │ Len bytes         │ 2 bytes  │
└──────────┴──────────┴────────┴────────┴──────────────────┴──────────┘
                                                │                      │
                                                └─ CRC16 over ────────┘
                                     CRC 计算范围: Type + Len + Payload
                                     CRC: CRC16-CCITT, poly=0x1021, init=0xFFFF
```

| 偏移 | 大小 | 字段 | 说明 |
|---|---|---|---|
| 0 | 2 | Header | `0xAA 0x55` |
| 2 | 1 | Type | `0x01`=遥测, `0x02`=指令 |
| 3 | 1 | Len | Payload 字节数 |
| 4 | Len | Payload | 见下文结构体定义 |
| 4+Len | 2 | CRC16 | LSB first, 覆盖 Offset 2 到 4+Len-1 |

### 帧长速查

| 帧类型 | Payload | 总帧长 |
|---|---|---|
| 遥测 (0x01) | **96 bytes** | **102 bytes** |
| 指令 (0x02) | **25 bytes** | **31 bytes** |

---

## 二、遥测帧（STM32 → ROS2, Type=0x01, 100Hz）

### Python struct 解包格式

```python
TLM_FORMAT = '<23f4B'       # 23个float + 4个uint8, little-endian, packed
TLM_SIZE   = 23*4 + 4       # = 96 bytes
```

### 字段表

| 序号 | 字段 | Python struct | 单位 | 说明 |
|---|---|---|---|---|
| 0 | timestamp | f | s | 下位机启动后秒数 (DWT) |
| 1 | roll | f | rad | IMU 横滚角 |
| 2 | pitch | f | rad | IMU 俯仰角 |
| 3 | yaw | f | rad | IMU 偏航角 |
| 4 | gyro_x | f | rad/s | 机体 X 轴角速度 |
| 5 | gyro_y | f | rad/s | 机体 Y 轴角速度 |
| 6 | gyro_z | f | rad/s | 机体 Z 轴角速度 |
| 7 | accel_x | f | m/s² | 世界系 X 轴加速度 |
| 8 | accel_y | f | m/s² | 世界系 Y 轴加速度 |
| 9 | accel_z | f | m/s² | 世界系 Z 轴加速度 |
| 10 | vel_n | f | m/s | 世界系水平速度 |
| 11 | pos_n | f | m | 世界系水平位移 |
| 12 | theta_L | f | rad | 左腿摆角 |
| 13 | L0_L | f | m | 左腿等效腿长 |
| 14 | wheel_T_L | f | Nm | 左轮毂输出力矩 |
| 15 | Tp_L | f | Nm | 左髋关节输出力矩 |
| 16 | d_theta_L | f | rad/s | 左腿摆角速度 |
| 17 | theta_R | f | rad | 右腿摆角 |
| 18 | L0_R | f | m | 右腿等效腿长 |
| 19 | wheel_T_R | f | Nm | 右轮毂输出力矩 |
| 20 | Tp_R | f | Nm | 右髋关节输出力矩 |
| 21 | d_theta_R | f | rad/s | 右腿摆角速度 |
| 22 | battery_voltage | f | V | 电池电压 |
| 23 | start_flag | B | — | 0=停止, 1=运行 |
| 24 | jump_flag | B | — | 跳跃状态机阶段 (0=无跳跃) |
| 25 | contact_L | B | — | 左腿着地 (0=离地, 1=着地) |
| 26 | contact_R | B | — | 右腿着地 (0=离地, 1=着地) |

### 坐标系说明

- **gyro / body frame**: X=前, Y=左, Z=上 (ENU-like body)
- **accel / world frame**: 绝对水平坐标系 (MotionAccel_n)
- **roll/pitch/yaw**: 经 EKF 融合后的欧拉角
- **vel_n / pos_n**: 世界系水平面内沿运动方向的速度和位移（由 INS 积分）

---

## 三、指令帧（ROS2 → STM32, Type=0x02）

### Python struct 打包格式

```python
CMD_FORMAT = '<6fB'         # 6个float + 1个uint8, little-endian, packed
CMD_SIZE   = 6*4 + 1        # = 25 bytes
```

### 字段表

| 序号 | 字段 | Python struct | 单位 | 说明 |
|---|---|---|---|---|
| 0 | timestamp | f | s | ROS2 时间戳 (ros::Time::now().toSec()) |
| 1 | v_set | f | m/s | 目标前进速度 (>0 前进) |
| 2 | yaw_rate_set | f | rad/s | 目标偏航角速度 (>0 左转) |
| 3 | roll_set | f | rad | 目标横滚角 (范围建议 ±0.4) |
| 4 | leg_set | f | m | 目标腿长 (范围 0.072~0.165) |
| 5 | pitch_set | f | rad | 俯仰偏移量 |
| 6 | cmd_flags | B | — | 控制标志位 |

### cmd_flags 位定义

| Bit | 宏 | 值 | 说明 |
|-----|-----|-----|---|
| 0 | `ROS2_CMD_ENABLE` | 0x01 | **使能底盘控制** — 必须置1下位机才响应 |
| 1 | `ROS2_CMD_JUMP` | 0x02 | 触发跳跃序列 (上升沿, 两腿同时起跳) |
| 2 | `ROS2_CMD_ESTOP` | 0x04 | 紧急停止 (最高优先级, 忽略其他位) |
| 3 | `ROS2_CMD_RECOVER` | 0x08 | 倒地自起 |

### 下位机行为细节

- **正常控制**: `cmd_flags=0x01` + 有效运动参数 → 下位机积分 `yaw_rate_set` 和 `v_set` 更新目标位姿
- **跳跃**: `cmd_flags=0x03` (ENABLE+JUMP) → 仅在 `jump_flag==0` 时触发一次
- **急停**: `cmd_flags=0x04` → 立即关闭电机, 回零所有目标
- **自起**: `cmd_flags=0x08` → 进入倒地恢复模式 (leg_set 强制 0.08m)
- **超时保护**: 下位机连续 **100 ms** 未收到有效 `ENABLE` 指令时, 自动停车

---

## 四、上位机实现要点

### 4.1 串口打开

```python
import serial
ser = serial.Serial('/dev/ttyACM0', baudrate=115200, timeout=0.01)
# baudrate 对 USB CDC 是虚拟的, 设为任意值均可
```

### 4.2 帧同步与解析

> ⚠️ CDC 传输可能将一帧拆成多个 USB 包, 必须用字节级状态机拼帧，**不能假设一次 read 就是一帧**。

```python
HEADER = b'\xaa\x55'

class FrameParser:
    def __init__(self):
        self.buf = bytearray()
        self.state = 'WAIT_H0'

    def feed(self, byte: int) -> bytes | None:
        """每次喂 1 个字节, 收到完整帧时返回 payload bytes, 否则返回 None"""
        self.buf.append(byte)
        if self.state == 'WAIT_H0':
            if byte == 0xAA:
                self.state = 'WAIT_H1'
            else:
                self.buf.clear()
        elif self.state == 'WAIT_H1':
            if byte == 0x55:
                self.state = 'WAIT_TYPE'
            elif byte != 0xAA:
                self.state = 'WAIT_H0'
                self.buf.clear()
            else:
                self.buf = bytearray([0xAA])
        elif self.state == 'WAIT_TYPE':
            self.state = 'WAIT_LEN'
        elif self.state == 'WAIT_LEN':
            self.payload_len = byte
            self.state = 'WAIT_DATA'
        elif self.state == 'WAIT_DATA':
            hdr_len = 4
            needed = hdr_len + self.payload_len + 2  # +2 for CRC
            if len(self.buf) >= needed:
                frame = bytes(self.buf[:needed])
                self.buf.clear()
                self.state = 'WAIT_H0'
                # verify CRC
                crc_calc = crc16_ccitt(frame[2:hdr_len + self.payload_len + 2])
                if crc_calc == 0:
                    return frame[hdr_len:hdr_len + self.payload_len]
        return None
```

### 4.3 CRC16-CCITT

```python
def crc16_ccitt(data: bytes) -> int:
    """匹配下位机的 CRC16-CCITT, poly=0x1021, init=0xFFFF"""
    crc = 0xFFFF
    for b in data:
        crc ^= (b << 8)
        for _ in range(8):
            if crc & 0x8000:
                crc = (crc << 1) ^ 0x1021
            else:
                crc <<= 1
            crc &= 0xFFFF
    return crc
```

### 4.4 遥测解析

```python
import struct

TLM_FMT = '<23f4B'
TLM_SIZE = struct.calcsize(TLM_FMT)  # 96

def parse_telemetry(payload: bytes) -> dict:
    fields = struct.unpack(TLM_FMT, payload)
    return {
        'timestamp':       fields[0],
        'roll':            fields[1],
        'pitch':           fields[2],
        'yaw':             fields[3],
        'gyro_x':          fields[4],
        'gyro_y':          fields[5],
        'gyro_z':          fields[6],
        'accel_x':         fields[7],
        'accel_y':         fields[8],
        'accel_z':         fields[9],
        'vel_n':           fields[10],
        'pos_n':           fields[11],
        'theta_L':         fields[12],
        'L0_L':            fields[13],
        'wheel_T_L':       fields[14],
        'Tp_L':            fields[15],
        'd_theta_L':       fields[16],
        'theta_R':         fields[17],
        'L0_R':            fields[18],
        'wheel_T_R':       fields[19],
        'Tp_R':            fields[20],
        'd_theta_R':       fields[21],
        'battery_voltage': fields[22],
        'start_flag':      fields[23],
        'jump_flag':       fields[24],
        'contact_L':       fields[25],
        'contact_R':       fields[26],
    }
```

### 4.5 指令打包

```python
import struct

CMD_FMT = '<6fB'

def pack_command(timestamp: float, v_set: float, yaw_rate: float,
                 roll: float, leg: float, pitch: float,
                 enable: bool, jump: bool = False) -> bytes:
    flags = 0
    if enable:
        flags |= 0x01
    if jump:
        flags |= 0x02
    payload = struct.pack(CMD_FMT, timestamp, v_set, yaw_rate,
                          roll, leg, pitch, flags)
    # 组帧
    frame = bytearray([0xAA, 0x55, 0x02, len(payload)])
    frame += payload
    crc_data = frame[2:]
    crc = crc16_ccitt(crc_data + b'\x00\x00')  # placeholder
    # 实际需要计算后填入
    crc2 = crc16_ccitt(crc_data)
    frame += struct.pack('<H', crc2)
    return bytes(frame)
```

### 4.6 ROS2 话题映射建议

| STM32 数据 | ROS2 Topic | ROS2 Msg Type |
|---|---|---|
| roll/pitch/yaw | `/imu/data` | `sensor_msgs/Imu` |
| gyro_x/y/z | (同上) | |
| accel_x/y/z | (同上) | |
| vel_n, pos_n | `/odom` | `nav_msgs/Odometry` |
| theta_L/R, L0_L/R, d_theta_L/R | `/joint_states` | `sensor_msgs/JointState` |
| wheel_T_L/R, Tp_L/R | `/effort_states` | 自定义或 `/joint_states` effort 字段 |
| battery_voltage | `/battery` | `sensor_msgs/BatteryState` |
| contact_L/R | `/contact` | 自定义或 `std_msgs/Bool` |
| start_flag, jump_flag | `/state` | 自定义 |

| ROS2 控制源 | STM32 字段 | 说明 |
|---|---|---|
| `cmd_vel.linear.x` | `v_set` | 前进速度 |
| `cmd_vel.angular.z` | `yaw_rate_set` | 偏航角速度 |
| 自定义 topic `/cmd_attitude` | `roll_set` | 横滚角 |
| 自定义 topic `/cmd_attitude` | `leg_set` | 腿长 |
| `/cmd_estop` (Bool) | `cmd_flags | 0x04` | 急停 |
| `/cmd_jump` (Bool) | `cmd_flags | 0x02` | 跳跃 |

---

## 五、下位机源码位置

| 文件 | 内容 |
|---|---|
| `User/APP/ROS/ros2_task.h` | 协议常量、结构体定义 |
| `User/APP/ROS/ros2_task.c` | FreeRTOS 任务、CRC、帧打包/解包、数据采集、指令执行 |
| `USB_DEVICE/App/usbd_cdc_if.c` | CDC 接收通知 (ros2_cdc_rx_ready) |
| `Core/Src/freertos.c` | ROS_Task 注册 (优先级 Normal, 栈 1024 words) |

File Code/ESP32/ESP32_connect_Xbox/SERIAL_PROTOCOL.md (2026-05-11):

# Xbox 手柄串口通信协议

## 概述

ESP32-C3 通过蓝牙 BLE 连接 Xbox Series X 手柄后，将手柄的摇杆、扳机、按键数据封装为 11 字节的二进制帧，通过 Serial1（GPIO 20 TX / GPIO 21 RX，115200 8N1）每约 10ms 发送一帧。

## 数据帧格式

| 字节偏移 | 字段 | 类型 | 说明 |
|---:|---|---|---|
| 0 | header[0] | uint8 | 包头，固定值 `0x07` |
| 1 | header[1] | uint8 | 包头，固定值 `0x21` |
| 2 | joyL_X | uint8 | 左摇杆 X，原始值 -100~100，传输值 28~228（+128 偏移） |
| 3 | joyL_Y | uint8 | 左摇杆 Y，原始值 -100~100，传输值 28~228（+128 偏移） |
| 4 | joyR_X | uint8 | 右摇杆 X，原始值 -100~100，传输值 28~228（+128 偏移） |
| 5 | joyR_Y | uint8 | 右摇杆 Y，原始值 -100~100，传输值 28~228（+128 偏移） |
| 6 | trig_L | uint8 | 左扳机 LT，范围 0~100 |
| 7 | trig_R | uint8 | 右扳机 RT，范围 0~100 |
| 8 | buttons_1 | uint8 | 按钮组 1（位域打包） |
| 9 | buttons_2 | uint8 | 按钮组 2（位域打包） |
| 10 | checksum | uint8 | 前 10 字节求和取低 8 位 |

## 按钮位域

### buttons_1（字节 8）

| 位 | 按键 | 说明 |
|--:|---|---|
| 0 | A | 按下为 1 |
| 1 | LB | 左肩键 |
| 2 | RB | 右肩键 |
| 3 | Xbox | Xbox 导航键 |
| 4 | - | 保留 |
| 5 | - | 保留 |
| 6 | - | 保留 |
| 7 | - | 保留 |

### buttons_2（字节 9）

| 位 | 按键 | 说明 |
|--:|---|---|
| 0 | B | 按下为 1 |
| 1 | X | 按下为 1 |
| 2 | Y | 按下为 1 |
| 3 | - | 保留 |
| 4 | - | 保留 |
| 5 | - | 保留 |
| 6 | - | 保留 |
| 7 | - | 保留 |

## 摇杆数据换算

手柄原始摇杆值为 `uint16_t`（范围 0~65535），中心约为 32768。发送方将其归一化到 -100~100 后偏移 128 写入帧。

### 发送方编码（ESP32）

```
joy_value = (int)((raw - 32768.0) / 32768.0 * 100.0)  // X 轴
joy_value = -(int)((raw - 32768.0) / 32768.0 * 100.0) // Y 轴（取反）
frame_byte = (uint8_t)(joy_value + 128)
```

- 摇杆 Y 轴经取反处理，因此**向上为正（>128），向下为负（<128）**
- 摇杆 X 轴**向右为正（>128），向左为负（<128）**

### 接收方解码

```
joy_value = (int)frame_byte - 128   // 范围 -100~100，正=右/上，负=左/下
```

## 扳机数据换算

手柄原始扳机值为 `uint16_t`（范围 0~1023）。发送方将其归一化到 0~100 后写入帧。

```
trig_value = (int)(raw / 1023.0 * 100.0)
frame_byte = (uint8_t)(trig_value)  // 直接用原值，无偏移
```

## 校验和计算

```cpp
uint16_t checksum = 0;
for (int i = 0; i < 10; i++) {
    checksum += data[i];
}
data[10] = (uint8_t)(checksum & 0xFF);  // 取低 8 位
```

接收方验证方式：对前 10 个字节求和取低 8 位，与 `data[10]` 比较即可。不考虑进位回卷。

## 完整帧示例

以下为示例帧（假设摇杆居中、扳机松开、无按键按下）：

```
07 21 80 80 80 80 00 00 00 00 48
│     │  │  │  │  │  │  │  │  └─ checksum
│     │  │  │  │  │  │  │  └──── buttons_2 = 0 (B/X/Y 均未按下)
│     │  │  │  │  │  │  └─────── buttons_1 = 0 (A/LB/RB/Xbox 均未按下)
│     │  │  │  │  │  └────────── trig_R = 0
│     │  │  │  │  └───────────── trig_L = 0
│     │  │  │  └──────────────── joyR_Y = 0x80 (128, 居中)
│     │  │  └─────────────────── joyR_X = 0x80 (128, 居中)
│     │  └────────────────────── joyL_Y = 0x80 (128, 居中)
│     └───────────────────────── joyL_X = 0x80 (128, 居中)
└─────────────────────────── header
```

校验和：`0x07 + 0x21 + 0x80×4 + 0 + 0 + 0 + 0 = 0x07 + 0x21 + 0x200 = 0x228`，取低 8 位得 `0x28`。

## 双向通信

协议支持双向数据交换：

- **输出方向（ESP32 → 对端）**：每 10ms 发送一帧上述 11 字节数据
- **输入方向（对端 → ESP32）**：对端发送相同格式的帧（包头 `0x07 0x21`），ESP32 检测到包头后自动触发手柄 250ms 振动，带 300ms 冷却防抖

输入方向的帧只需要正确匹配前 2 字节包头，后续字节不影响振动触发。

## 注意事项

- 帧发送频率约为 100Hz（每 10ms 一帧），接收方需自行处理去抖和死区
- 校验和仅覆盖前 10 字节，不覆盖校验和自身
- 若需使用其他按钮（Select、Start、Share、LS、RS、十字键），可扩展 buttons_2 的保留位

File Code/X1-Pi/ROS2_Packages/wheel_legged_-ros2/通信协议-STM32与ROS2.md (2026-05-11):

# 轮足机器人 STM32–ROS2 通信协议

> 下位机：STM32H723VGT6 + FreeRTOS + USB CDC (VCP)  
> 物理层：USB OTG HS Full-Speed (12 Mbps), 虚拟串口 `/dev/ttyACM0`  
> 遥测频率：100 Hz  
> 指令频率：上限 100 Hz（建议 ≥50 Hz 以维持使能状态）

---

## 一、帧格式（统一格式）

```
┌──────────┬──────────┬────────┬────────┬──────────────────┬──────────┐
│ Header0  │ Header1  │ Type   │ Len    │ Payload          │ CRC16    │
│ 0xAA     │ 0x55     │ 1 byte │ 1 byte │ Len bytes         │ 2 bytes  │
└──────────┴──────────┴────────┴────────┴──────────────────┴──────────┘
                                                │                      │
                                                └─ CRC16 over ────────┘
                                     CRC 计算范围: Type + Len + Payload
                                     CRC: CRC16-CCITT, poly=0x1021, init=0xFFFF
```

| 偏移 | 大小 | 字段 | 说明 |
|---|---|---|---|
| 0 | 2 | Header | `0xAA 0x55` |
| 2 | 1 | Type | `0x01`=遥测, `0x02`=指令 |
| 3 | 1 | Len | Payload 字节数 |
| 4 | Len | Payload | 见下文结构体定义 |
| 4+Len | 2 | CRC16 | LSB first, 覆盖 Offset 2 到 4+Len-1 |

### 帧长速查

| 帧类型 | Payload | 总帧长 |
|---|---|---|
| 遥测 (0x01) | **96 bytes** | **102 bytes** |
| 指令 (0x02) | **25 bytes** | **31 bytes** |

---

## 二、遥测帧（STM32 → ROS2, Type=0x01, 100Hz）

### Python struct 解包格式

```python
TLM_FORMAT = '<23f4B'       # 23个float + 4个uint8, little-endian, packed
TLM_SIZE   = 23*4 + 4       # = 96 bytes
```

### 字段表

| 序号 | 字段 | Python struct | 单位 | 说明 |
|---|---|---|---|---|
| 0 | timestamp | f | s | 下位机启动后秒数 (DWT) |
| 1 | roll | f | rad | IMU 横滚角 |
| 2 | pitch | f | rad | IMU 俯仰角 |
| 3 | yaw | f | rad | IMU 偏航角 |
| 4 | gyro_x | f | rad/s | 机体 X 轴角速度 |
| 5 | gyro_y | f | rad/s | 机体 Y 轴角速度 |
| 6 | gyro_z | f | rad/s | 机体 Z 轴角速度 |
| 7 | accel_x | f | m/s² | 世界系 X 轴加速度 |
| 8 | accel_y | f | m/s² | 世界系 Y 轴加速度 |
| 9 | accel_z | f | m/s² | 世界系 Z 轴加速度 |
| 10 | vel_n | f | m/s | 世界系水平速度 |
| 11 | pos_n | f | m | 世界系水平位移 |
| 12 | theta_L | f | rad | 左腿摆角 |
| 13 | L0_L | f | m | 左腿等效腿长 |
| 14 | wheel_T_L | f | Nm | 左轮毂输出力矩 |
| 15 | Tp_L | f | Nm | 左髋关节输出力矩 |
| 16 | d_theta_L | f | rad/s | 左腿摆角速度 |
| 17 | theta_R | f | rad | 右腿摆角 |
| 18 | L0_R | f | m | 右腿等效腿长 |
| 19 | wheel_T_R | f | Nm | 右轮毂输出力矩 |
| 20 | Tp_R | f | Nm | 右髋关节输出力矩 |
| 21 | d_theta_R | f | rad/s | 右腿摆角速度 |
| 22 | battery_voltage | f | V | 电池电压 |
| 23 | start_flag | B | — | 0=停止, 1=运行 |
| 24 | jump_flag | B | — | 跳跃状态机阶段 (0=无跳跃) |
| 25 | contact_L | B | — | 左腿着地 (0=离地, 1=着地) |
| 26 | contact_R | B | — | 右腿着地 (0=离地, 1=着地) |

### 坐标系说明

- **gyro / body frame**: X=前, Y=左, Z=上 (ENU-like body)
- **accel / world frame**: 绝对水平坐标系 (MotionAccel_n)
- **roll/pitch/yaw**: 经 EKF 融合后的欧拉角
- **vel_n / pos_n**: 世界系水平面内沿运动方向的速度和位移（由 INS 积分）

---

## 三、指令帧（ROS2 → STM32, Type=0x02）

### Python struct 打包格式

```python
CMD_FORMAT = '<6fB'         # 6个float + 1个uint8, little-endian, packed
CMD_SIZE   = 6*4 + 1        # = 25 bytes
```

### 字段表

| 序号 | 字段 | Python struct | 单位 | 说明 |
|---|---|---|---|---|
| 0 | timestamp | f | s | ROS2 时间戳 (ros::Time::now().toSec()) |
| 1 | v_set | f | m/s | 目标前进速度 (>0 前进) |
| 2 | yaw_rate_set | f | rad/s | 目标偏航角速度 (>0 左转) |
| 3 | roll_set | f | rad | 目标横滚角 (范围建议 ±0.4) |
| 4 | leg_set | f | m | 目标腿长 (范围 0.072~0.165) |
| 5 | pitch_set | f | rad | 俯仰偏移量 |
| 6 | cmd_flags | B | — | 控制标志位 |

### cmd_flags 位定义

| Bit | 宏 | 值 | 说明 |
|-----|-----|-----|---|
| 0 | `ROS2_CMD_ENABLE` | 0x01 | **使能底盘控制** — 必须置1下位机才响应 |
| 1 | `ROS2_CMD_JUMP` | 0x02 | 触发跳跃序列 (上升沿, 两腿同时起跳) |
| 2 | `ROS2_CMD_ESTOP` | 0x04 | 紧急停止 (最高优先级, 忽略其他位) |
| 3 | `ROS2_CMD_RECOVER` | 0x08 | 倒地自起 |

### 下位机行为细节

- **正常控制**: `cmd_flags=0x01` + 有效运动参数 → 下位机积分 `yaw_rate_set` 和 `v_set` 更新目标位姿
- **跳跃**: `cmd_flags=0x03` (ENABLE+JUMP) → 仅在 `jump_flag==0` 时触发一次
- **急停**: `cmd_flags=0x04` → 立即关闭电机, 回零所有目标
- **自起**: `cmd_flags=0x08` → 进入倒地恢复模式 (leg_set 强制 0.08m)
- **超时保护**: 下位机连续 **100 ms** 未收到有效 `ENABLE` 指令时, 自动停车

---

## 四、上位机实现要点

### 4.1 串口打开

```python
import serial
ser = serial.Serial('/dev/ttyACM0', baudrate=115200, timeout=0.01)
# baudrate 对 USB CDC 是虚拟的, 设为任意值均可
```

### 4.2 帧同步与解析

> ⚠️ CDC 传输可能将一帧拆成多个 USB 包, 必须用字节级状态机拼帧，**不能假设一次 read 就是一帧**。

```python
HEADER = b'\xaa\x55'

class FrameParser:
    def __init__(self):
        self.buf = bytearray()
        self.state = 'WAIT_H0'

    def feed(self, byte: int) -> bytes | None:
        """每次喂 1 个字节, 收到完整帧时返回 payload bytes, 否则返回 None"""
        self.buf.append(byte)
        if self.state == 'WAIT_H0':
            if byte == 0xAA:
                self.state = 'WAIT_H1'
            else:
                self.buf.clear()
        elif self.state == 'WAIT_H1':
            if byte == 0x55:
                self.state = 'WAIT_TYPE'
            elif byte != 0xAA:
                self.state = 'WAIT_H0'
                self.buf.clear()
            else:
                self.buf = bytearray([0xAA])
        elif self.state == 'WAIT_TYPE':
            self.state = 'WAIT_LEN'
        elif self.state == 'WAIT_LEN':
            self.payload_len = byte
            self.state = 'WAIT_DATA'
        elif self.state == 'WAIT_DATA':
            hdr_len = 4
            needed = hdr_len + self.payload_len + 2  # +2 for CRC
            if len(self.buf) >= needed:
                frame = bytes(self.buf[:needed])
                self.buf.clear()
                self.state = 'WAIT_H0'
                # verify CRC
                crc_calc = crc16_ccitt(frame[2:hdr_len + self.payload_len + 2])
                if crc_calc == 0:
                    return frame[hdr_len:hdr_len + self.payload_len]
        return None
```

### 4.3 CRC16-CCITT

```python
def crc16_ccitt(data: bytes) -> int:
    """匹配下位机的 CRC16-CCITT, poly=0x1021, init=0xFFFF"""
    crc = 0xFFFF
    for b in data:
        crc ^= (b << 8)
        for _ in range(8):
            if crc & 0x8000:
                crc = (crc << 1) ^ 0x1021
            else:
                crc <<= 1
            crc &= 0xFFFF
    return crc
```

### 4.4 遥测解析

```python
import struct

TLM_FMT = '<23f4B'
TLM_SIZE = struct.calcsize(TLM_FMT)  # 96

def parse_telemetry(payload: bytes) -> dict:
    fields = struct.unpack(TLM_FMT, payload)
    return {
        'timestamp':       fields[0],
        'roll':            fields[1],
        'pitch':           fields[2],
        'yaw':             fields[3],
        'gyro_x':          fields[4],
        'gyro_y':          fields[5],
        'gyro_z':          fields[6],
        'accel_x':         fields[7],
        'accel_y':         fields[8],
        'accel_z':         fields[9],
        'vel_n':           fields[10],
        'pos_n':           fields[11],
        'theta_L':         fields[12],
        'L0_L':            fields[13],
        'wheel_T_L':       fields[14],
        'Tp_L':            fields[15],
        'd_theta_L':       fields[16],
        'theta_R':         fields[17],
        'L0_R':            fields[18],
        'wheel_T_R':       fields[19],
        'Tp_R':            fields[20],
        'd_theta_R':       fields[21],
        'battery_voltage': fields[22],
        'start_flag':      fields[23],
        'jump_flag':       fields[24],
        'contact_L':       fields[25],
        'contact_R':       fields[26],
    }
```

### 4.5 指令打包

```python
import struct

CMD_FMT = '<6fB'

def pack_command(timestamp: float, v_set: float, yaw_rate: float,
                 roll: float, leg: float, pitch: float,
                 enable: bool, jump: bool = False) -> bytes:
    flags = 0
    if enable:
        flags |= 0x01
    if jump:
        flags |= 0x02
    payload = struct.pack(CMD_FMT, timestamp, v_set, yaw_rate,
                          roll, leg, pitch, flags)
    # 组帧
    frame = bytearray([0xAA, 0x55, 0x02, len(payload)])
    frame += payload
    crc_data = frame[2:]
    crc = crc16_ccitt(crc_data + b'\x00\x00')  # placeholder
    # 实际需要计算后填入
    crc2 = crc16_ccitt(crc_data)
    frame += struct.pack('<H', crc2)
    return bytes(frame)
```

### 4.6 ROS2 话题映射建议

| STM32 数据 | ROS2 Topic | ROS2 Msg Type |
|---|---|---|
| roll/pitch/yaw | `/imu/data` | `sensor_msgs/Imu` |
| gyro_x/y/z | (同上) | |
| accel_x/y/z | (同上) | |
| vel_n, pos_n | `/odom` | `nav_msgs/Odometry` |
| theta_L/R, L0_L/R, d_theta_L/R | `/joint_states` | `sensor_msgs/JointState` |
| wheel_T_L/R, Tp_L/R | `/effort_states` | 自定义或 `/joint_states` effort 字段 |
| battery_voltage | `/battery` | `sensor_msgs/BatteryState` |
| contact_L/R | `/contact` | 自定义或 `std_msgs/Bool` |
| start_flag, jump_flag | `/state` | 自定义 |

| ROS2 控制源 | STM32 字段 | 说明 |
|---|---|---|
| `cmd_vel.linear.x` | `v_set` | 前进速度 |
| `cmd_vel.angular.z` | `yaw_rate_set` | 偏航角速度 |
| 自定义 topic `/cmd_attitude` | `roll_set` | 横滚角 |
| 自定义 topic `/cmd_attitude` | `leg_set` | 腿长 |
| `/cmd_estop` (Bool) | `cmd_flags | 0x04` | 急停 |
| `/cmd_jump` (Bool) | `cmd_flags | 0x02` | 跳跃 |

---

## 五、AI 提示词模板

以下提示词可直接发给 AI 助手以生成 ROS2 上位机 Python 代码:

---

### 基础版提示词

```
我有一台通过 USB CDC 虚拟串口与 STM32 通信的轮足机器人, 需要编写
ROS2 (Humble) Python 节点, 实现双向通信。请根据以下协议完成代码:

1. 物理连接: /dev/ttyACM0, 波特率对 CDC 无效可忽略
2. 帧格式: 0xAA 0x55 | Type(1B) | Len(1B) | Payload(Len B) | CRC16(2B LSB)
   - CRC16-CCITT: poly=0x1021, init=0xFFFF, 覆盖 Type+Len+Payload
3. 遥测帧 (Type=0x01): 96 bytes payload, Python struct 格式 '<23f4B'
   字段: timestamp, roll, pitch, yaw, gyro_x, gyro_y, gyro_z,
         accel_x, accel_y, accel_z, vel_n, pos_n,
         theta_L, L0_L, wheel_T_L, Tp_L, d_theta_L,
         theta_R, L0_R, wheel_T_R, Tp_R, d_theta_R,
         battery_voltage, start_flag, jump_flag, contact_L, contact_R
4. 指令帧 (Type=0x02): 25 bytes payload, Python struct 格式 '<6fB'
   字段: timestamp, v_set, yaw_rate_set, roll_set, leg_set, pitch_set, cmd_flags
   cmd_flags: bit0=使能, bit1=跳跃, bit2=急停, bit3=倒地自起
5. 遥测 100Hz 持续发送; 需要字节级状态机拼帧 (CDC 可能拆包)
6. 发布 topic: /imu (sensor_msgs/Imu), /odom (nav_msgs/Odometry),
   /joint_states (sensor_msgs/JointState), /battery (sensor_msgs/BatteryState)
7. 订阅 topic: /cmd_vel (geometry_msgs/Twist) 映射到 v_set + yaw_rate_set
8. 每 100ms 无指令自动超时停止 (需要节点持续发心跳指令)
9. 用 rclpy.spin_once 或 timer 驱动主循环, 不要阻塞在串口读
```

### 进阶版提示词（含更多上下文）

```
[在此粘贴本 .md 文档全文]

请在 ROS2 Humble + Python 中实现完整的上位机通信节点, 要求:
- 类名: WheelFootBridge
- 自动检测 /dev/ttyACM* 并连接
- 100Hz 遥测解析 + 50Hz 指令下发 (两个独立定时器)
- 订阅 /cmd_vel 映射为 v_set/yaw_rate_set
- 订阅 /cmd_attitude (自定义 Float32MultiArray: [roll, pitch, leg])
- 服务 /enable 和 /estop 控制启停
- 参数: port, telemetry_rate, cmd_rate, timeout_ms
- 线程安全的串口帧解析
- launch 文件
```

---

## 六、下位机源码位置

| 文件 | 内容 |
|---|---|
| `User/APP/ROS/ros2_task.h` | 协议常量、结构体定义 |
| `User/APP/ROS/ros2_task.c` | FreeRTOS 任务、CRC、帧打包/解包、数据采集、指令执行 |
| `USB_DEVICE/App/usbd_cdc_if.c` | CDC 接收通知 (ros2_cdc_rx_ready) |
| `Core/Src/freertos.c` | ROS_Task 注册 (优先级 Normal, 栈 1024 words) |

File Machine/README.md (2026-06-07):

## 文件目录

- **3D打印件**— 机器人前后面板和结构件的3D打印文件，可直接导入切片软件进行打印
- **机加工件**— CNC和玻纤板的机加工文件
- **SolidWorks**— 机器人机械结构的SolidWorks设计文件，包含装配体和各个零件

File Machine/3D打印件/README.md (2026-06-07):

# 3D 打印件

机器人外壳和结构件的 3D 打印文件，可直接导入切片软件进行打印。

## 打印清单

| 零件名称 | 数量 | 文件名 |
| --- | :--: | --- |
| 前挡板 | 1 | `前挡板.STEP` |
| 后挡板 | 1 | `后挡板.STEP` |
| 轮毂打印件-内圈 | 2 | `轮毂打印件-内圈.STEP` |
| 上握把 | 1 | `上握把.STEP` |
| 深度相机支架 | 1 | `深度相机支架.STEP` |
| LD06 雷达转接架 | 1 | `LD06雷达转接架.STEP` |
| 显示屏支架 | 1 | `显示屏支架.STEP` |

## 打印建议

- 推荐材料： PETG
- 填充密度：30%
- 壁厚：3 层
- 轮毂内圈为受力件，建议提高填充密度至 50%

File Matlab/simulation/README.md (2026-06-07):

# 轮腿式平衡机器人仿真

基于达妙开源轮腿机器人仿真项目，目录包含机器人的 Simulink 动力学模型及 LQR 控制器设计相关 MATLAB 脚本。

> 参考论文：**《轮腿式平衡机器人控制》** — 陈阳

---

## 文件说明

| 文件 | 类型 | 说明 |
|---|---|---|
| `blance_leg2.slx` | Simulink 模型 | 轮腿平衡机器人主仿真模型，集成了动力学模型和 LQR 控制器 |
| `get_k_length.m` | MATLAB 函数 | 根据腿长 `leg_length` 建立状态空间模型，求解 LQR 最优增益矩阵 `K`（2×6）。基于拉格朗日动力学推导，包含驱动轮、摆杆（腿）、机体三部分耦合模型 |
| `get_k.m` | MATLAB 脚本 | 批量调用 `get_k_length` 计算不同腿长（0.1~0.21m）下的 K 矩阵，进行三次多项式拟合，并输出 `fp32` 格式的 C 语言数组，供嵌入式端（STM32）直接使用 |
| `VMC_calc.m` | MATLAB 函数 | 虚拟模型控制（VMC）计算：给定期望力 `F0` 和髋关节扭矩 `Tp`，通过雅可比矩阵换算为上/下关节电机扭矩 `Tp1`、`Tp2` |
| `d_phi0.m` | MATLAB 脚本 | 符号计算：推导机体姿态（`L0`、`phi0`）对关节角度（`phi1`、`phi4`）的雅可比矩阵，用于运动学分析 |
| `v_angle_FixedTorque.m` | MATLAB 脚本 | 跳跃能力验证：在恒定扭矩下求解角度-角速度二阶微分方程，计算机架速度随大腿角度的变化曲线，判断是否满足最小起跳速度 |

---

## 使用方式

### 环境要求

- **MATLAB R2021a 或更高版本**（需 Simulink + Control System Toolbox + Symbolic Math Toolbox）

### 运行步骤

1. **生成 LQR 增益矩阵**
   ```matlab
   run('get_k.m')
   ```
   该脚本会：
   - 遍历不同腿长，调用 `get_k_length` 计算 LQR 增益 `K`
   - 对 K 矩阵的 12 个元素分别做三次多项式拟合
   - 在 Workspace 中生成默认腿长（0.14m）对应的 `K` 变量
   - 输出 `fp32` 格式的 C 数组系数，可直接复制到嵌入式代码

2. **打开 Simulink 模型仿真**
   ```matlab
   open_system('blance_leg2')
   ```
   确认 Workspace 中已有 `K` 矩阵后，运行仿真观察机器人平衡控制的动态响应。

3. **跳跃能力验证（可选）**
   ```matlab
   run('v_angle_FixedTorque.m')
   ```
   绘制机架速度-大腿角度曲线，验证扭矩是否满足起跳条件。

### 关键参数

| 参数 | 值 | 说明 |
|---|-----|---|
| 驱动轮半径 `R` | 0.0625 m | — |
| 腿长范围 | 0.10 ~ 0.21 m | 可调 |
| 默认腿长 | 0.14 m | `get_k.m` 中设定 |
| 机体质量 `M` | 2.087 kg | — |
| 腿总质量 `mp` | 3.887 kg | 两条腿 |
| 轮总质量 `mw` | 1.210 kg | 两个驱动轮 |
| 机器人总重 | ~7.18 kg | — |

---

## 控制架构

```
期望状态 → [LQR 增益 K] → [轮扭矩 T, 髋扭矩 Tp] → 轮腿动力学模型 → 实际状态
                ↑                                              |
                └──────────── 状态反馈 ─────────────────────────┘
```

- **状态量**（6维）：`[theta, d_theta, x, d_x, phi, d_phi]` — 摆杆角/角速度、轮位移/速度、机体角/角速度
- **控制量**（2维）：`[T, Tp]` — 驱动轮扭矩、髋关节扭矩
- **LQR 加权**：Q 矩阵侧重速度跟踪和姿态稳定，R 矩阵限制控制输出幅值

---

## 模型说明

Simulink 模型 `blance_leg2.slx` 基于以下假设：

- 机器人简化为三刚体模型：**驱动轮** + **摆杆（腿）** + **机体**
- 驱动轮与地面间无滑动（纯滚动约束）
- 髋关节为理想旋转副，无摩擦
- 俯仰角（phi）和摆杆角（theta）均为小角度附近线性化

VMC（虚拟模型控制）通过运动学雅可比将任务空间力/力矩映射到关节空间力矩，相关推导见 `d_phi0.m`。

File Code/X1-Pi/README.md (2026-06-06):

# X1-Pi 代码

Rhino-Pi X1 机器人上位机代码，运行于 Aidlux 平台，涵盖 ROS2 底层控制、语音交互、表情显示、LLM 推理等模块。

## 系统架构

```
┌──────────────────────────────────────────────────────────┐
│                      X1-Pi (Aidlux)                       │
│                                                          │
│  ┌──────────────┐  ┌──────────────┐  ┌───────────────┐   │
│  │ ROS2_Packages│  │HA_Voice      │  │ emotion_display│   │
│  │ 轮足机器人控制 │  │Assistant     │  │ GIF 表情播放器  │   │
│  │ SLAM/导航     │  │ASR/TTS/KWS   │  │ FIFO 命令切换  │   │
│  └──────┬───────┘  └──────┬───────┘  └───────┬───────┘   │
│         │                 │                   │           │
│         ▼                 ▼                   ▼           │
│  ┌──────────────────────────────────────────────────┐    │
│  │              共享通信层 (FIFO / ROS2)              │    │
│  └──────────────────────────────────────────────────┘    │
│         │                 │                   │           │
│  ┌──────┴───────┐  ┌──────┴───────┐  ┌───────┴───────┐   │
│  │   Vision     │  │   Aid_LLM    │  │  Home Assistant│   │
│  │  (规划中)     │  │ Qwen3-4B NPU │  │  Conversation │   │
│  └──────────────┘  └──────────────┘  └───────────────┘   │
└──────────────────────────────────────────────────────────┘
```

## 模块说明

### [`ROS2_Packages`](ROS2_Packages/)
ROS2 底层功能包，包含轮足机器人核心控制代码：
- 机器人运动控制与状态管理
- LD06/LD19/STL27L 激光雷达驱动
- STM32 与 ROS2 通信协议（串口）
- SLAM 建图与导航（含 Web 可视化）
- 启动脚本与地图文件

> 详见 [wheel_legged_-ros2/README.md](ROS2_Packages/wheel_legged_-ros2/README.md) 和 [通信协议文档](ROS2_Packages/wheel_legged_-ros2/通信协议-STM32与ROS2.md)

### [`HA_VoiceAssistant`](HA_VoiceAssistant/)
Home Assistant 智能语音助手，本地部署 ASR/TTS/KWS 模型：
- **KWS 唤醒词检测** — sherpa-onnx Zipformer，本地离线唤醒
- **ASR 语音识别** — AidVoice NPU SenseVoice，NPU 加速推理
- **TTS 语音合成** — VITS-Piper，流式合成与播放
- **Wyoming STT 服务器** — 将 ASR 注册为 HA 语音转文字引擎
- **外部管道模式** — 独立 KWS + ASR 管道，通过 HA Conversation API 交互

> 详见 [HA_VoiceAssistant/README.md](HA_VoiceAssistant/README.md)

### [`emotion_display`](emotion_display/)
全屏 GIF 表情播放器，用于机器人情感化交互：
- PySide6 全屏窗口 + QMovie 播放
- 支持 14 种表情 GIF（待机/开心/难过/生气/睡眠等）
- 运行时通过命名管道 `/tmp/gif_cmd` 动态切换表情
- 支持 GNOME + Wayland 开机自启动

> 详见 [emotion_display/README.md](emotion_display/README.md) 和 [emotion_display/DEPLOY.md](emotion_display/DEPLOY.md)

### [`Aid_LLM`](Aid_LLM/)
LLM 推理模块 — 通过 AidGenSE 在 NPU 上部署 Qwen3-4B-Instruct 实现本地对话推理。

### [`Vision`](Vision/)
视觉交互模块 — 体感交互、手势/姿态识别等功能。

---

## 硬件依赖

| 模块 | 硬件要求 |
|---|---|
| ROS2_Packages | X1 轮足机器人底盘、STM32 主控、激光雷达 (LD06/19/STL27L) |
| HA_VoiceAssistant | 麦克风阵列、扬声器、NPU (AidVoice) |
| emotion_display | HDMI 显示器 |
| Aid_LLM | NPU (Aidlux) |

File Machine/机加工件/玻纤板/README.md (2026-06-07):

# 玻纤板加工件

轮毂盖片的玻纤板加工文件。

## 加工清单

| 零件名称 | 数量 | 文件名 |
| --- | :--: | --- |
| 轮毂-上盖片 | 2 | `轮毂-上盖片.STEP` |
| 轮毂-下盖片 | 2 | `轮毂-下盖片.STEP` |

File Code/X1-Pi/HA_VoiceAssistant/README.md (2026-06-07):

# HA 语音助手 - AidVoice NPU 语音转文字 + HA Conversation API

基于 sherpa-onnx KWS、AidVoice NPU SenseVoice ASR 和 Home Assistant Conversation API 的智能语音助手。

## 系统架构

```
                         ┌──────────────────────────────────────┐
                         │      Home Assistant (Docker)         │
                         │                                      │
  ┌──────┐   Wyoming     │  ┌─────────────┐  ┌───────────────┐  │
  │ STT  │◄── TCP ───────┼──┤ Assist 管道  │  │ Conversation  │  │
  │Server│   :10300      │  │ (STT 客户端) │──┤ Agent         │  │
  └──┬───┘              │  └─────────────┘  │(extended_openai│  │
     │                  │                    └───────┬───────┘  │
  ┌──┴──────────┐       │                            │          │
  │ AidVoiceASR │       │                    ┌───────┴───────┐  │
  │(NPU SenseVoice)     │                    │  TTS (可选)   │  │
  └─────────────┘       └────────────────────┴───────────────┘  │

  ┌─────────────────────────────────────────────────────────┐
  │  外部语音管道（可选，与 Wyoming STT 互补）                │
  │                                                         │
  │  麦克风 → KWS(唤醒词) → ASR(AidVoice NPU) → HA API → TTS│
  └─────────────────────────────────────────────────────────┘
```

本仓库提供两种工作模式：
1. **Wyoming STT 模式** — 将 AidVoice 注册为 HA 的语音转文字引擎，完全融入 Assist 管道
2. **外部管道模式** — 外部 KWS + ASR 检测唤醒词后，通过 HA REST API 调用对话助手

## 目录结构

```
HA_VoiceAssistant/
├── __init__.py              # 包入口
├── config.py                # 配置管理（KWS/TTS/HA）
├── state.py                 # 线程安全状态机
├── audio.py                 # ALSA 麦克风采集
├── wakeword.py              # sherpa-onnx 关键词唤醒检测
├── asr_aidvoice.py          # AidVoice NPU SenseVoice 语音识别
├── asr_bridge.cpp           # NPU ASR C 桥接源码
├── asr_bridge.h             # NPU ASR C 桥接头文件
├── asr_bridge.so            # NPU ASR C 动态库（预编译）
├── tts.py                   # VITS-Piper 语音合成 + 流式播放
├── ha_client.py             # HA Conversation API 客户端
├── pipeline.py              # 流水线编排（KWS → ASR → HA API → TTS）
├── start.py                 # 外部管道模式入口
├── start.sh                 # 外部管道模式启动脚本
├── keys.txt                 # HA 长期访问令牌（用户自行填写）
├── migrate/                 # 迁移部署指南
│   └── README.md
├── stt_server/              # Wyoming STT 服务器
│   ├── __init__.py
│   ├── server.py            # AidVoice Wyoming STT 服务端
│   └── start.sh             # STT 服务器启动脚本
└── models/                  # 模型文件
    ├── sherpa-onnx-kws-zipformer-wenetspeech-3.3M-2024-01-01/
    │   ├── encoder-epoch-12-avg-2-chunk-16-left-64.int8.onnx
    │   ├── decoder-epoch-12-avg-2-chunk-16-left-64.int8.onnx
    │   ├── joiner-epoch-12-avg-2-chunk-16-left-64.int8.onnx
    │   ├── tokens.txt
    │   ├── keywords.txt
    │   └── keywords_raw.txt
    └── vits-piper-zh_CN-xiao_ya-medium-fp16/
        ├── zh_CN-xiao_ya-medium.fp32.onnx
        ├── tokens.txt
        ├── lexicon.txt
        ├── date.fst
        ├── number.fst
        └── phone.fst
```

## 前置条件

### 安装依赖

```bash
pip install sherpa-onnx sounddevice requests numpy wyoming
```

### HA 长期访问令牌

在 HA 中创建长期访问令牌（设置 → 长期访问令牌 → 创建），保存到 `keys.txt`：

```
HA_TOKEN=你的令牌内容
```

## Wyoming STT 服务器（推荐）

将 AidVoice NPU SenseVoice 注册为 HA 的语音转文字引擎。

### 启动服务器

```bash
cd /home/aidlux/MIC_ASR/HA_VoiceAssistant
bash stt_server/start.sh
```

默认监听 `tcp://0.0.0.0:10300`。

### HA 配置

在 `configuration.yaml` 中添加：

```yaml
wyoming:
  - server: localhost
    port: 10300
```

重启 HA，进入 设置 → 语音助手 → Assist Pipeline：
- 新建或编辑管道
- **语音转文字** 选择 "AidVoice SenseVoice"
- **对话代理** 选择你的助手（如 Qwen3-4B-8550）
- **文字转语音** 按需选择

## 外部管道模式（外部 KWS + TTS）

此模式下，外部脚本负责唤醒词检测和 ASR，识别结果通过 HA API 发送。

### 启动

```bash
cd /home/aidlux/MIC_ASR/HA_VoiceAssistant
bash start.sh
```

### 参数说明

| 参数 | 说明 | 默认值 |
|---|---|---|
| `--kws-encoder` | KWS encoder ONNX 路径 | 必填 |
| `--kws-decoder` | KWS decoder ONNX 路径 | 必填 |
| `--kws-joiner` | KWS joiner ONNX 路径 | 必填 |
| `--kws-tokens` | KWS tokens.txt 路径 | 必填 |
| `--kws-keywords` | keywords.txt 路径 | 必填 |
| `--kws-num-threads` | KWS 推理线程数 | `1` |
| `--kws-threshold` | 唤醒灵敏度阈值 | `0.10` |
| `--kws-score` | 关键词加分值 | `1.5` |
| `--tts-model` | TTS 模型 ONNX 路径 | 必填 |
| `--tts-tokens` | TTS tokens.txt 路径 | 必填 |
| `--tts-lexicon` | TTS lexicon.txt 路径 | `""` |
| `--tts-rule-fsts` | 文本归一化 FST 文件（逗号分隔） | `""` |
| `--tts-speed` | 语速 (>1 更快) | `1.0` |
| `--tts-mode` | TTS 播报模式，`sentence` 逐句 / `full` 整段 | `sentence` |
| `--volume-gain` | 音量增益 | `1.0` |
| `--asr-cooldown-ms` | TTS 回复后的冷却期（毫秒） | `1200` |
| `--ha-url` | HA 服务器地址 | `http://localhost:8123` |
| `--ha-agent-id` | 对话助手 agent_id | `conversation.qwen3_4b_8550` |
| `--ha-timeout` | HTTP 请求超时（秒） | `30` |
| `--device-name` | ALSA 录音设备 | `plughw:2,0` |
| `--playback-device` | ALSA 播放设备名，留空自动检测 | `""` |

### 唤醒词列表

创建 `keywords_raw.txt`，每行写中文唤醒词，空格用下划线代替：

```
小爱同学 @小爱同学
你好军哥 @你好军哥
```

使用 `sherpa-onnx-cli text2token` 工具转为拼音 token 格式：

```bash
sherpa-onnx-cli text2token \
  --tokens models/sherpa-onnx-kws-zipformer-wenetspeech-3.3M-2024-01-01/tokens.txt \
  --tokens-type ppinyin \
  keywords_raw.txt keywords.txt
```

生成的文件格式如下：

```
x iǎo ài t óng x ué @小爱同学
n ǐ h ǎo j ūn g ē @你好军哥
```

放入模型目录覆盖原文件，重启助手即可生效。

## TTS 播报模式

支持两种播报方式，通过 `--tts-mode` 参数切换：

| 模式 | 参数 | 行为 |
|---|---|---|
| **逐句播报** | `--tts-mode sentence`（默认） | 按标点拆分为句子，逐句合成播放，延迟低 |
| **整段播报** | `--tts-mode full` | 整段文本一次合成后播放 |

```bash
# 整段播报
./start.sh --tts-mode full
```

## 迁移到其他机器

同型号设备迁移部署请参考 [migrate/README.md](migrate/README.md)。

## Wyoming 协议说明

STT 服务基于 [Wyoming 协议](https://www.home-assistant.io/integrations/wyoming/) 实现：

1. **Describe/Info** — 服务发现，HA 查询可用的 ASR 模型
2. **Transcribe** — 启动转录会话
3. **AudioStart/AudioChunk/AudioStop** — 流式传输音频（16kHz, 16-bit PCM, 单声道）
4. **Transcript** — 返回识别文本

音频格式转换：PCM s16le 字节流 → float32 numpy 数组（归一化到 [-1, 1]）

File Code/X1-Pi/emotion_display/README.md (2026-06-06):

# Emotion Display

全屏 GIF 表情播放器，支持通过命名管道在运行时动态切换表情、调整循环间隔。

## 目录结构

```
emotion_display/
├── main.py          # 入口
├── gif_player.py    # 全屏窗口 + QMovie + 状态机
├── fifo_handler.py  # FIFO 命令监听与解析
└── gif_source/      # 14 个表情 GIF
```

## 环境要求

- Python >= 3.8
- PySide6

```bash
pip install PySide6
```

## 启动

```bash
cd emotion_display
python3 main.py
```

启动后全屏播放 `standby.gif`，无限循环，间隔 2 秒。

按 **Esc** 或 **Q** 退出。

## 运行时命令

从另一个终端通过命名管道 `/tmp/gif_cmd` 发送命令：

### 切换表情

```bash
echo "play happy"         > /tmp/gif_cmd   # 无限循环，保持当前间隔
echo "play sad 3"         > /tmp/gif_cmd   # 播放 3 次后停止，保持当前间隔
echo "play sad 3 0"       > /tmp/gif_cmd   # 播放 3 次，间隔 0s（连播）
echo "play enjoy 0 0.5"   > /tmp/gif_cmd   # 无限循环，间隔 0.5s
```

`play` 命令完整格式：`play <表情名> [次数] [间隔秒数]`，次数默认 0（无限），间隔不指定则保持当前值。

### 调整间隔

```bash
echo "interval 1.5" > /tmp/gif_cmd    # 循环间隔改为 1.5 秒
```

### 暂停/恢复

```bash
echo "stop" > /tmp/gif_cmd            # 暂停
echo "resume" > /tmp/gif_cmd          # 恢复播放
```

### 退出

```bash
echo "quit" > /tmp/gif_cmd            # 退出程序
```

## 可用表情

| 文件名 | 对应命令 |
|---|---|
| afraid.gif | `play afraid` |
| angery.gif | `play angery` |
| charging\&like.gif | `play charging&like` |
| cold.gif | `play cold` |
| dizz.gif | `play dizz` |
| enjoy.gif | `play enjoy` |
| happy.gif | `play happy` |
| kick.gif | `play kick` |
| sad.gif | `play sad` |
| sad\&tear.gif | `play sad&tear` |
| shutdown.gif | `play shutdown` |
| sleep.gif | `play sleep` |
| standby.gif | `play standby` |
| voice.gif | `play voice` |

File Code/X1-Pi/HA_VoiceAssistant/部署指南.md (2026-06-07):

# HA 语音助手 — 部署指南

将语音助手部署到**X1派**的完整步骤。

---

## 一、环境要求

| 项目 | 要求 |
|---|---|
| 架构 | ARM aarch64 |
| 平台 | Qualcomm QCS8550 |
| 外设 | USB 麦克风 + 音箱 |
| Python | >= 3.8 |

---

## 二、准备工作

### 2.1 确认 AidLux 授权状态

```bash
aid-lms-check
```

输出应包含 `"isActive": true`。若未激活，参考 [AidLux 授权激活文档](https://rhinopi.docs.aidlux.com/software/aidlux/developer-guide/developer-guide-activation) 激活。

### 2.2 安装 AidVoice SDK

```bash
sudo aid-pkg update
sudo aid-pkg install aidlite-sdk
sudo aid-pkg install aidlite-qnn236
sudo aid-pkg -i aidvoice-sdk
```

验证安装：

```bash
ls -l /usr/local/lib/libaidvoice_speech.so
ls /usr/local/include/aidlux/aidvoice/aidvoice_speech.hpp
```

### 2.3 安装 Python 依赖

```bash
pip3 install sherpa-onnx sounddevice requests numpy wyoming
```

### 2.4 安装系统音频库

```bash
sudo apt update
sudo apt install -y alsa-utils libportaudio2 pulseaudio
```

---

## 三、编译 asr_bridge.so

`asr_bridge.so` 是连接 Python 和 AidVoice C++ SDK 的桥梁，需要从源码编译。

### 3.1 准备源码

两个源码文件已包含在项目目录中：

```bash
ls -l ~/HA_VoiceAssistant/asr_bridge.cpp
ls -l ~/HA_VoiceAssistant/asr_bridge.h
```

### 3.2 编译

```bash
cd ~/HA_VoiceAssistant

g++ -std=c++17 -fPIC -shared \
    -I/usr/local/include \
    -L/usr/local/lib \
    -laidvoice_speech \
    -lpthread \
    -o asr_bridge.so \
    asr_bridge.cpp
```

### 3.3 验证编译结果

```bash
file asr_bridge.so
# 预期输出: ... ELF 64-bit LSB shared object, ARM aarch64 ...

# 检查符号
nm -D asr_bridge.so | grep asr_bridge_create
# 应输出类似: 0000000000000xxx T asr_bridge_create
```

---

## 四、文件检查

### 4.1 确认关键文件完整

```bash
cd ~/HA_VoiceAssistant
ls -l asr_bridge.so
ls -l models/sherpa-onnx-kws-zipformer-wenetspeech-3.3M-2024-01-01/encoder-epoch-12-avg-2-chunk-16-left-64.int8.onnx
ls -l models/vits-piper-zh_CN-xiao_ya-medium-fp16/zh_CN-xiao_ya-medium.fp32.onnx
```

### 4.2 KEYS.TXT 注意事项

`keys.txt` 包含 Home Assistant 令牌，**必须重新创建**

```bash
# 清空旧的令牌
echo "" > ~/HA_VoiceAssistant/keys.txt
```

---

## 五、配置 Home Assistant

### 5.1 创建 HA 长期访问令牌

1. 浏览器打开 `http://目标机器IP:8123`
2. 进入 **设置 → 长期访问令牌 → 创建令牌**
3. 复制令牌内容

### 5.2 写入 keys.txt

```bash
echo "HA_TOKEN=你创建的令牌" > ~/HA_VoiceAssistant/keys.txt
```

### 5.3 确认对话代理

启动脚本默认使用 agent_id：`conversation.qwen3_4b_8550`。如果 HA 中配置了其他对话代理，启动时需指定：

```bash
./start.sh --ha-agent-id conversation.你的代理id
```

---

## 六、音频设备配置

### 6.1 检测录音设备

```bash
arecord -l
```

示例输出：

```
card 0: Pro [ASTRA Pro], device 0: USB Audio [USB Audio]
card 1: kalamaqrdsndcar [kalama-qrd-snd-card], device 5: CODEC_DMA-...
```

麦克风通常是 USB 设备（card 0），记下 `card X, device Y`。

### 6.2 检测播放设备

```bash
aplay -l
```

音箱通常是 USB 或板载音频输出，记下 `card X, device Y`。

### 6.3 修改启动脚本

编辑 `start.sh`，修改设备名：

```bash
# 麦克风（更换为检测到的设备）
DEVICE_NAME="plughw:0,0"

# 播放设备（更换为检测到的设备）
PLAYBACK_DEVICE="plughw:0,0"
```

---

## 七、启动验证

### 7.1 启动语音助手

```bash
cd ~/HA_VoiceAssistant
./start.sh
```

看到以下输出即启动成功：

```
HA 语音助手已启动
说唤醒词开始对话，按 Ctrl+C 退出
```

### 7.2 功能测试

| 测试步骤 | 预期结果 |
|---|---|
| 说唤醒词"小爱同学" | 控制台输出 `[唤醒] 小爱同学` |
| 接着说"今天天气怎么样" | ASR 识别出文字，输出 `[用户] 今天天气怎么样` |
| 等待 HA 回复 | 控制台输出 `[助手] ...` |
| TTS 播报 | 音箱播放语音回复 |

---

## 八、配置唤醒词

唤醒词使用 sherpa-onnx 的 Keyword Spotting 引擎，模型已预训练好，只需提供关键词列表即可。预设唤醒词为 "小爱同学"。

### 8.1 关键词文件位置

```
~/HA_VoiceAssistant/models/sherpa-onnx-kws-zipformer-wenetspeech-3.3M-2024-01-01/
├── keywords.txt        # 模型使用的唤醒词文件
├── keywords_raw.txt    # （可选）原始唤醒词，便于修改
└── tokens.txt          # 拼音 token 映射表
```

### 8.2 文件格式说明

`sherpa-onnx-kws-zipformer-wenetspeech-3.3M-2024-01-01` 模型使用**拼音 token** 表示唤醒词。

**`keywords.txt`**（模型直接使用）：

```
x iǎo ài t óng x ué @小爱同学
```

每行格式：`拼音token（空格分隔） @ 显示文本`

**`keywords_raw.txt`**（供 `text2token` 工具使用）：

```
小爱同学 @小爱同学
```

> 关键词中不能包含空格，多词组合请用下划线 `_` 连接。

### 8.3 使用 text2token 工具生成

`sherpa_onnx` pip 包自带 `sherpa-onnx-cli text2token` 工具，可将中文文本自动转为拼音 token：

**步骤 1**：创建 `keywords_raw.txt`

```bash
cd ~/HA_VoiceAssistant/models/sherpa-onnx-kws-zipformer-wenetspeech-3.3M-2024-01-01

cat > keywords_raw.txt << 'EOF'
小爱同学 @小爱同学
EOF
```

**步骤 2**：转换为 `keywords.txt`

```bash
sherpa-onnx-cli text2token \
  --tokens tokens.txt \
  --tokens-type ppinyin \
  keywords_raw.txt keywords.txt
```

**步骤 3**：验证生成结果

```bash
cat keywords.txt
# 输出：
# x iǎo ài t óng x ué @小爱同学
```

### 8.4 替换并重启

```bash
# 确认 keywords.txt 已更新
cp keywords.txt ~/HA_VoiceAssistant/models/sherpa-onnx-kws-zipformer-wenetspeech-3.3M-2024-01-01/

# 重启语音助手
~/HA_VoiceAssistant/./start.sh
```

### 8.5 调整唤醒灵敏度

通过 `--kws-threshold` 参数控制：

```bash
# 阈值越低越灵敏（默认 0.10）
./start.sh --kws-threshold 0.08    # 更灵敏
./start.sh --kws-threshold 0.15    # 更迟钝（减少误唤醒）
```

> 如果自定义唤醒词后始终无法触发，可尝试降低阈值。

### 8.6 多唤醒词建议

- 每个唤醒词建议 2~4 个汉字，太短容易误唤醒，太长用户说着累
- 中文唤醒词直接写汉字即可，工具会自动转为拼音 token
- 英文唤醒词需使用 BPE 模型（本项目模型仅支持中文）

---

## 九、常见问题

### Q: TTS 播放无声音

```
Expression 'alsa_snd_pcm_prepare( stream->playback.pcm )' failed
```

**原因**：播放设备配置错误或 PulseAudio 未运行。

**解决**：
```bash
# 确认 PulseAudio 运行中
pulseaudio --check

# 如果未运行
pulseaudio --start

# 检查播放设备名称是否正确
python3 -c "import sounddevice as sd; print(sd.query_devices())"
```

### Q: 唤醒不灵敏或误唤醒

**原因**：阈值过低或过高。

**解决**：
```bash
# 调低阈值（更灵敏）
./start.sh --kws-threshold 0.08

# 调高阈值（减少误唤醒）
./start.sh --kws-threshold 0.15
```

### Q: VAD 不触发，ASR 不输出

**原因**：VAD 能量阈值与麦克风不匹配。

**解决**：编辑 `asr_aidvoice.py`，调整 `_SPEECH_ENERGY_THRESHOLD` 值：

```python
_SPEECH_ENERGY_THRESHOLD = 0.02  # 默认值，麦克风噪音大可调高到 0.05
```

---

## 十、参考链接

- [AidVoice SDK 官方文档](https://rhinopi.docs.aidlux.com/software/aidvoice/aidvoice_guide)
- [AidLux 系统部署](https://rhinopi.docs.aidlux.com/software/aidlux/system-use/aidlux-installation)
- [AidLux 授权激活](https://rhinopi.docs.aidlux.com/software/aidlux/developer-guide/developer-guide-activation)
- [sherpa-onnx 文档](https://github.com/k2-fsa/sherpa-onnx)

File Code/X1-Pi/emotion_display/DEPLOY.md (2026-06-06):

# Emotion Display — 部署指南

## 目录

- [环境要求](#环境要求)
- [安装依赖](#安装依赖)
- [项目结构](#项目结构)
- [手动启动](#手动启动)
- [开机自启动（GNOME + Wayland）](#开机自启动gnome--wayland)
- [运行时命令](#运行时命令)
- [常见问题](#常见问题)

---

## 环境要求

| 组件 | 要求 |
|---|---|
| OS | Ubuntu 22.04+ (arm64) |
| Python | >= 3.8 |
| PySide6 | >= 6.5 |
| 显示器 | HDMI 单屏（默认全屏到主显示器） |

## 安装依赖

```bash
# 1. 安装 PySide6
pip3 install PySide6

# 2. 安装系统依赖（Qt XCB 平台插件）
sudo apt install -y libxcb-cursor0
```

## 项目结构

```
emotion_display/
├── main.py           # 入口：组装 GifPlayer + FifoHandler
├── gif_player.py     # 全屏窗口 + QMovie 播放 + 状态机
├── fifo_handler.py   # FIFO 命令监听与解析
├── start.sh          # 启动脚本（封装环境变量）
├── DEPLOY.md         # 本部署文档
├── README.md         # 项目说明与命令参考
└── gif_source/       # 14 个表情 GIF
    ├── standby.gif   # 待机（默认启动显示）
    ├── happy.gif
    ├── sad.gif
    ├── sad&tear.gif
    ├── angery.gif
    ├── afraid.gif
    ├── cold.gif
    ├── dizz.gif
    ├── enjoy.gif
    ├── kick.gif
    ├── voice.gif
    ├── sleep.gif
    ├── charging&like.gif
    └── shutdown.gif
```

## 手动启动

```bash
cd /home/aidlux/qt_-dev/emotion_display
python3 main.py
```

启动后全屏播放 `standby.gif`，无限循环，循环间隔 2 秒。

按 **Esc** 或 **Q** 退出。

## 开机自启动（GNOME + Wayland）

### 背景说明

本系统使用 GNOME + Wayland。PySide6 在 Wayland 原生模式下全屏窗口（`showFullScreen()`）存在已知兼容问题，因此启动脚本通过 `QT_QPA_PLATFORM=xcb` 强制使用 XCB 后端。

### 步骤

#### 1. 启动脚本 `start.sh`

已创建于项目根目录：

```bash
#!/bin/bash
export DISPLAY=:0
export QT_QPA_PLATFORM=xcb
cd /home/aidlux/qt_-dev/emotion_display
python3 main.py
```

#### 2. GNOME 自启动项

已创建于 `~/.config/autostart/emotion-display.desktop`：

```ini
[Desktop Entry]
Type=Application
Name=Emotion Display
Exec=/home/aidlux/qt_-dev/emotion_display/start.sh
X-GNOME-Autostart-enabled=true
X-GNOME-Autostart-Delay=5
```

- **延迟 5 秒**：等桌面环境完全就绪后再启动。
- **启用状态**：`X-GNOME-Autostart-enabled=true`。

#### 3. 生效

重启 GNOME 会话（注销重登或重启系统）后自动生效。

如需临时禁用，删除或重命名 desktop 文件：

```bash
mv ~/.config/autostart/emotion-display.desktop ~/.config/autostart/emotion-display.desktop.bak
```

## 运行时命令

通过命名管道 `/tmp/gif_cmd` 发送命令（从另一终端）：

### 切换表情

```bash
echo "play happy"         > /tmp/gif_cmd   # 无限循环，保持当前间隔
echo "play sad 3"         > /tmp/gif_cmd   # 播放 3 次后停止
echo "play sad 3 0"       > /tmp/gif_cmd   # 播放 3 次，间隔 0s（连播）
echo "play enjoy 0 0.5"   > /tmp/gif_cmd   # 无限循环，间隔 0.5s
```

格式：`play <表情名> [循环次数] [间隔秒数]`

- 表情名对应 `gif_source/` 下的文件名（不含 `.gif`）
- 循环次数：`0` = 无限循环，`3` = 播放 3 次后暂停
- 间隔秒数：不指定则保持当前值

### 调整循环间隔

```bash
echo "interval 1.5" > /tmp/gif_cmd    # 改为 1.5 秒
```

### 暂停 / 恢复

```bash
echo "stop"   > /tmp/gif_cmd           # 暂停
echo "resume" > /tmp/gif_cmd           # 恢复播放
```

### 退出

```bash
echo "quit" > /tmp/gif_cmd
```

### 可用表情

| 命令 | 对应文件 |
|---|---|
| `play afraid` | afraid.gif |
| `play angery` | angery.gif |
| `play charging&like` | charging&like.gif |
| `play cold` | cold.gif |
| `play dizz` | dizz.gif |
| `play enjoy` | enjoy.gif |
| `play happy` | happy.gif |
| `play kick` | kick.gif |
| `play sad` | sad.gif |
| `play sad&tear` | sad&tear.gif |
| `play shutdown` | shutdown.gif |
| `play sleep` | sleep.gif |
| `play standby` | standby.gif |
| `play voice` | voice.gif |

## 常见问题

### Qt 报错 "xcb-cursor0 or libxcb-cursor0 is needed"

```bash
sudo apt install -y libxcb-cursor0
```

### PySide6 未安装

```bash
pip3 install PySide6
```

确认安装成功：

```bash
python3 -c "from PySide6.QtWidgets import QApplication; print('OK')"
```

### 启动后窗口不显示

检查是否已设置 `DISPLAY`：

```bash
echo $DISPLAY    # 应为 :0
```

若使用 Wayland 但未强制 XCB，可先尝试：

```bash
export QT_QPA_PLATFORM=xcb
python3 main.py
```

### 自启动后程序未运行

检查 desktop 文件：

```bash
ls -la ~/.config/autostart/emotion-display.desktop
```

检查启动日志（如果有输出重定向）：

```bash
cat /tmp/emotion_display.log
```

尝试手动执行 `start.sh` 确认无误：

```bash
/home/aidlux/qt_-dev/emotion_display/start.sh
```

### 多显示器问题

当前仅支持单显示器（HDMI）。如需多显示器选屏，需修改 `gif_player.py`，使用 `QScreen` 指定目标屏幕。

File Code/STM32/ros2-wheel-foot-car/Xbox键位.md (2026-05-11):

# Xbox 手柄控制逻辑说明

本文档对应当前工程中的 `User/APP/xbox_task.c` 实现，用于说明 Xbox 手柄各按键/摇杆与底盘控制行为的映射关系。

## 1. 任务周期与数据更新

- 控制任务函数：`Xbox_task()`
- 任务周期：约 `55ms`（`osDelay(55)`）
- 每周期执行：
	1. 检查手柄是否超时断连
	2. 执行 `Xbox_data_process(&chassis_move, 0.055f)` 更新底盘目标

### 1.1 断连保护

- 若超过约 `51ms` 未收到新数据（`cur_time - last_time > 51`），会将 `xboxController` 全部清零。
- 清零后摇杆与按键等效于“无输入”。

---

## 2. 按键逻辑

当前底盘控制实际使用按键：`A`、`B`、`LB`、`RB`。

### 2.1 A 键：底盘启停切换（边沿触发）

- 触发条件：`A` 从未按下变为按下（上升沿）
- 逻辑：
	- 若 `start_flag == 0`：置 `start_flag = 1`（启动）
	- 若 `start_flag == 1`：置 `start_flag = 0`（关闭），并清 `recover_flag = 0`

> 说明：使用边沿触发，长按不会重复切换。

### 2.2 LB + RB 组合键：触发跳跃（边沿触发）

- 触发条件：`LB` 与 `RB` 同时按下，并且组合键由“未触发”变为“触发”（上升沿）
- 限制条件：`jump_flag == 0 && jump_flag2 == 0`
- 动作：
	- `jump_flag = 1`
	- `jump_flag2 = 1`

### 2.3 B 键：横滚复位（电平触发）

- 触发条件：`B` 为按下状态
- 动作：`roll_set = -0.03f`

> 说明：按住 `B` 时每个控制周期都会执行复位。

---

## 3. 摇杆逻辑

### 3.1 左摇杆：速度与转向

- `leftStickY` → 前后速度 `v_set`
	- 计算：`v_set = (-leftStickY) * 0.010f`
- `leftStickX` → 转向角目标增量 `turn_set`
	- 计算：`turn_set += (-leftStickX) * 0.00064f`
- 位置积分：`x_set += v_set * dt`，其中 `dt = 0.055f`

### 3.2 右摇杆：横滚与腿长

- `rightStickX` → 横滚目标 `roll_set`
	- 计算：`roll_set += (-rightStickX) * 0.00009f`
	- 限幅：`roll_set ∈ [-0.40, 0.40]`
- `rightStickY` → 腿长目标 `leg_set`
	- 计算：`leg_set += (-rightStickY) * 0.00002f`
	- 限幅：`leg_set ∈ [0.072, 0.21]`

### 3.3 腿长主动控制标志

- 若 `fabsf(last_leg_set - leg_set) > 0.0001f`：
	- `right.leg_flag = 1`
	- `left.leg_flag = 1`

---

## 4. 启动/关闭状态行为

### 4.1 启动状态（`start_flag == 1`）

- 按摇杆输入实时更新：速度、位置、转向、横滚、腿长。

### 4.2 关闭状态（`start_flag == 0`）

- 强制设置为安全默认目标：
	- `v_set = 0.0f`
	- `x_set = x_filter`
	- `turn_set = total_yaw`
	- `leg_set = 0.08f`
	- `roll_set = -0.03f`

---

## 5. 协议按键位映射（`p[8]`）

`Xbox_ProcessData()` 中当前按键位定义如下：

- `0x01`：`A`
- `0x02`：`LB`
- `0x04`：`RB`
- `0x08`：`Start`（当前底盘逻辑未使用）
- `0x10`：`B`

其余按键（`X/Y/Back/方向键`）当前解析后固定为 `false`，未参与控制。

---

## 6. 备注

- 本文档描述的是“当前代码实际行为”。
- 若后续修改了 `xbox_task.c` 中系数、限幅或按键位定义，请同步更新本文件。

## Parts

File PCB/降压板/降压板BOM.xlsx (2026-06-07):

No. | Quantity | Comment | Designator | Footprint | Value | Manufacturer Part | Manufacturer | Supplier Part | Supplier
1 | 1 | 100uF | C1 | C1210 | 100uF | CL32A107MQVNNNE | SAMSUNG(三星) | C49066 | LCSC
2 | 3 | XT30UPB-F30.G.Y | CN2,CN3,CN4 | CONN-TH_XT30UPB-F |  | XT30UPB-F30.G.Y | AMASS(艾迈斯) | C108769 | LCSC
3 | 2 | GL0805UG01 | LED1,LED3 | LED_0805 |  | GL0805UG01 | Guiguang light(桂光光电) | C51933308 | LCSC
4 | 3 | 10kΩ | R1,R2,R5 | R0805 | 10kΩ | 0805W8F1002T5E | UNI-ROYAL(厚声) | C17414 | LCSC
5 | 1 | 120Ω | R3 | R0603 | 120Ω | FRC0603F1200TS | FOJAN(富捷) | C2906988 | LCSC
6 | 1 | 3520 12V降压模块 | U1 | CR3520
7 | 1 | XT30U-M.G.B | U2 | CONN-TH_XT30U-M |  | XT30U-M.G.B | AMASS(艾迈斯) | C19268020 | LCSC
8 | 1 | ZXDN10S1205SAW | U4 | ZXDN10S最小封装 |  |  | 中兴
9 | 2 | TYPE-C 6P | USB1,USB2 | USB_ TYPE-C-6P |  | TYPE-C 6P | SHOU HAN(首韩) | C456012 | LCSC

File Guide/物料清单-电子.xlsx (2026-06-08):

电子部分的物料清单
电机
商品名称 | 数量 | 商品链接
伺泰威GIM6010-8-GHS68双编版本 | 4 | https://e.tb.cn/h.RjTvLsRJvvWV5K0?tk=T0ZtgcMxsrI
达妙DM-H6215 | 2
控制器
商品名称 | 数量
达妙DM-MC02开发板(STM32H723) | 1 | https://e.tb.cn/h.RQeCFhEXogUV3RT?tk=PiO8gcopaTp
犀牛派X1 | 1
线缆
商品名称 | 数量 | 商品链接
XT30 2+2 10cm连接线 | 4 | https://e.tb.cn/h.R9kllLwFKdFckqE?tk=ltyjgcMiNeD CZ028
XT30 公转母10cm连接线 | 1 | https://e.tb.cn/h.RjT2kASAGH76AEk?tk=2eSJgcMU2Am
XT30 公转公20cm连接线 | 1 | https://e.tb.cn/h.RjTeSO6zBMt2cCn?tk=717rgcM6pw5
GH1.25-2P 双头同向连接线 | 1 | https://e.tb.cn/h.R9kpRRDtlBeZRJu?tk=Z7cCgcMPwCE
GH1.25-2P 双头反向连接线 | 1 | https://e.tb.cn/h.R9kpRRDtlBeZRJu?tk=Z7cCgcMPwCE
USB转Type-C 0.15m数据线 | 1 | https://e.tb.cn/h.RQ3BR1Sea3ICNS0?tk=siflgcMpBYr
DC5525弯头转XT30 0.25m公头数据线 | 1 | https://e.tb.cn/h.RjTprohOPqD21Px?tk=ybzggcMHRWN
USB3.0拓展坞 | 1 | https://e.tb.cn/h.RjTtcGkJ4LBtpIL?tk=NvTigcMExtQ
HDMI 上弯头4mm 0.5m数据线 | 1 | https://e.tb.cn/h.R9PjPXLabjV7MsR?tk=s0DOgcoUdiA
USB转Type-C 0.25m弯头数据线 | 1 | https://e.tb.cn/h.Rj663mq5BvGzA7M?tk=0F3kgco8zyW
商品名称 | 数量 | 商品链接
7寸IPS-HDMI触摸显示器 | 1 | https://e.tb.cn/h.R9P5ClybYj900QC?tk=TTfVgco2fdN
奥比中光AstraPro深度相机 | 1 | https://e.tb.cn/h.Rj6YN9uOyQtTkNR?tk=raTfgcoWWLT
乐动LD-06激光雷达 | 1 | https://e.tb.cn/h.R8mYZBMvyD9IlTS?tk=BgUYgcoVh4M
CP2102 TTL模块 | 1 | https://e.tb.cn/h.Rj6PCqmeg3VsXt5?tk=mfMkgcomlPG
USB 10052音箱 | 1 | https://e.tb.cn/h.Rj6mjqfMyyArA9B?tk=Ezlhgconkh4
DJI Matrice 4D 电池 | 1 | https://e.tb.cn/h.Rj6Jqoaeakz4go8?tk=dnf4gcoIIWM
RoboMaster 电池架 | 1 | https://e.tb.cn/h.RQV1TtnHIyDQaoA?tk=TppwgcoGlvn
上电缓启动模块 | 1 | https://e.tb.cn/h.Rj6FbfnDzR5oCwH?tk=1SqOgcovrQk

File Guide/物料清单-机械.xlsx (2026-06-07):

机械部分物料清单
名称 | 数量 | 购买链接
M3-L10-内六角圆柱螺钉 | 100 | https://www.jlcfa.com/serial/2129403909149.html?codeModel=EDLA-S1&productModel=EDLA-S1-M3-L10
M3-L10扁平头内六角螺钉 | 100 | https://www.jlcfa.com/serial/1750094518794.html?codeModel=ELSW-S1W&productModel=ELSW-S1W-M3-L10
M2.5-L5扁平头内六角螺钉 | 100 | https://www.jlcfa.com/serial/1750094518794.html?codeModel=ELSW-S1W
M3-L30内六角圆柱螺钉 | 50 | https://www.jlcfa.com/serial/2129403909149.html?codeModel=EDLA-S1&productModel=EDLA-S1-M3-L30
M3-L20内六角圆柱螺钉 | 100 | https://www.jlcfa.com/serial/2129403909149.html?codeModel=EDLA-S1&productModel=EDLA-S1-M3-L20
M3-L8内六角圆柱螺钉 | 100 | https://www.jlcfa.com/serial/2129403909149.html?codeModel=EDLA-S1&productModel=EDLA-S1-M3-L8
M3-L40内六角圆柱螺钉 | 50 | https://www.jlcfa.com/serial/2129403909149.html?codeModel=EDLA-S1&productModel=EDLA-S1-M3-L40
M10-L20内六角圆柱螺钉 | 10 | https://www.jlcfa.com/serial/2129403909149.html?codeModel=EDLA-S1&productModel=EDLA-S1-M10-L20
M10-L30内六角圆柱螺钉 | 10 | https://www.jlcfa.com/serial/2129403909149.html?codeModel=EDLA-S1&productModel=EDLA-S1-M10-L30
M2-L6-内六角圆柱螺钉 | 100 | https://www.jlcfa.com/serial/2129403909149.html?codeModel=EDLA-S1&productModel=EDLA-S1-M2-L6
M4-L10内六角圆柱螺钉 | 100 | https://www.jlcfa.com/serial/2129403909149.html?codeModel=EDLA-S1&productModel=EDLA-S1-M4-L10
M4-L12内六角扁平头螺钉 | 100 | https://www.jlcfa.com/serial/1750094518794.html?codeModel=ELSW-S1W&productModel=ELSW-S1W-M4-L12
M2.9-L19自攻螺钉 | 50 | https://www.jlcfa.com/serial/1387281206242.html?codeModel=ELLE-S1W&productModel=ELLE-S1W-ST2.9-L19
M4-L16扁平头内六角螺钉 | 100 | https://www.jlcfa.com/serial/1750094518794.html?codeModel=ELSW-S1W&productModel=ELSW-S1W-M4-L16
M5-L10扁平头内六角螺钉 | 100 | https://www.jlcfa.com/serial/1750094518794.html?codeModel=ELSW-S1W&productModel=ELSW-S1W-M5-L10
M3-L10双通六角螺柱 | 24 | https://www.jlcfa.com/serial/1855384768557.html?codeModel=EJLD-U3&productModel=EJLD-U3-M3-L10
M3-L40双通六角螺柱 | 4 | https://www.jlcfa.com/serial/1855384768557.html?codeModel=EJLD-U3&productModel=EJLD-U3-M3-L40
M3-L10-V3单通六角螺柱 | 10 | https://www.jlcfa.com/serial/1771338885716.html?codeModel=EJLJ-U&productModel=EJLJ-U-M3-L10-3
M3*5+5转M2.5内牙螺柱 | 4 | https://e.tb.cn/h.RQEOWI92S4LutdI?tk=y09Cg1zzpe4
M3*5+5转M2内牙螺柱 | 4 | https://e.tb.cn/h.R8qGZX1UlYzJVQz?tk=3SWMg1AZJ8L
M3弹簧垫圈 | 200 | https://www.jlcfa.com/serial/2135521331445.html?codeModel=EPDB-S1W-B1&productModel=EPDB-S1W-B1-3
M5弹簧垫圈 | 200 | https://www.jlcfa.com/serial/2135521331445.html?codeModel=EPDB-S1W-B1&productModel=EPDB-S1W-B1-5
M10弹簧垫圈 | 100 | https://www.jlcfa.com/serial/2135521331445.html?codeModel=EPDB-S1W-B1&productModel=EPDB-S1W-B1-10
M4弹簧垫圈 | 200 | https://www.jlcfa.com/serial/2135521331445.html?codeModel=EPDB-S1W-B1&productModel=EPDB-S1W-B1-4
M3防松螺母 | 100 | https://www.jlcfa.com/serial/1668153340207.html?codeModel=EMLC-S1-N&productModel=EMLC-S1-N-M3
M4防松螺母 | 100 | https://www.jlcfa.com/serial/1668153340207.html?codeModel=EMLC-S1-N&productModel=EMLC-S1-N-M4
M5防松螺母 | 100 | https://www.jlcfa.com/serial/1668153340207.html?codeModel=EMLC-S1-N&productModel=EMLC-S1-N-M5
M10防松螺母 | 10 | https://www.jlcfa.com/serial/1668153340207.html?codeModel=EMLC-S1-N&productModel=EMLC-S1-N-M10A
6*6*30-M3长铝条 | 10 | https://e.tb.cn/h.RjNKQG5QzYIXqbf?tk=qNINg1AQHND
M10*16*0.5不锈钢垫片 | 50 | https://e.tb.cn/h.RQwXhRaKxjOptCz?tk=QeRbg1AlkQR
F6800ZZ深沟球法兰轴承 | 24 | https://www.jlcfa.com/item/1562771744551.html?fa_s=F6800ZZ&t=1780844435401
江昕5x2实心胎 | 2 | https://e.tb.cn/h.R8wrHbvZwhkahwT?tk=OJO2gcWyp2K

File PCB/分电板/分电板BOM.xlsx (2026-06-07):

No. | Quantity | Comment | Designator | Footprint | Value | Manufacturer Part | Manufacturer | Supplier Part | Supplier
1 | 1 | XT30PW-M | CN1 | CONN-TH_XT30PW-M |  | XT30PW-M | AMASS(艾迈斯) | C53373776 | LCSC
2 | 1 | XT60PW-M | CN2 | CONN-TH_XT60PW-M |  | XT60PW-M | AMASS(艾迈斯) | C98732 | LCSC
3 | 2 | WAFER-GH1.25-2PWB | CN3,CN4 | CONN-TH_2P-P1.25_XUNPU_WAFER-GH1.25-2PWB |  | WAFER-GH1.25-2PWB | XUNPU(讯普) | C3029377 | LCSC
4 | 2 | PZ254V-11-02P | H1,H2 | HDR-TH_2P-P2.54-V-M-2 |  | PZ254V-11-02P | XFCN(兴飞) | C492401 | LCSC
5 | 2 | 120Ω | R1,R2 | R0805 | 120Ω | 0805W8F1200T5E | UNI-ROYAL(厚声) | C17437 | LCSC
6 | 2 | TA-3525-A1 | SW1,SW2 | SW-SMD_3P-L9.1-W3.5-P2.50_BDKG-3P-H2MM |  | TA-3525-A1 | Yuandi(元迪) | C514018 | LCSC
7 | 6 | XT30(2+2)PW-M.G.B | U1,U2,U3,U4,U5,U6 | CONN-TH_4P-XT30PW-M |  | XT30(2+2)PW-M.G.B | AMASS(艾迈斯) | C19268030 | LCSC
8 | 1 | XT30PW-F20.G.Y | U7 | CONN-TH_XT30PW-F-1 |  | XT30PW-F20.G.Y | AMASS(艾迈斯) | C2913282 | LCSC

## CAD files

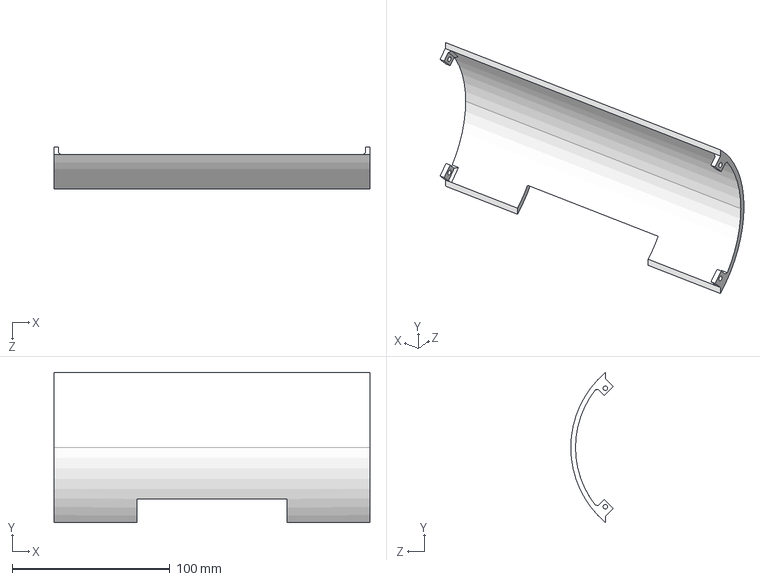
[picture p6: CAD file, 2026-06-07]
Machine/3D打印件/前挡板.STEP
200.0 x 95.0 x 26.9 mm

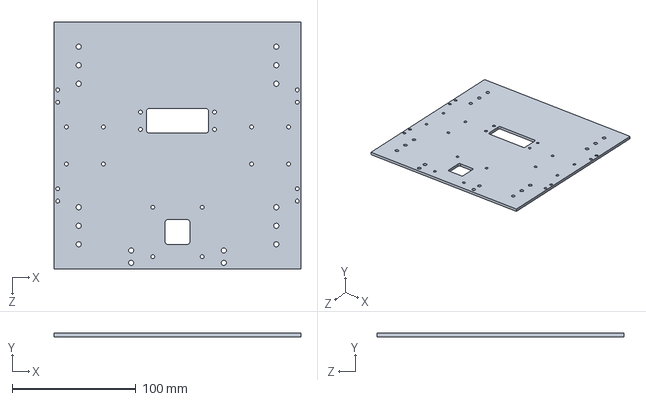
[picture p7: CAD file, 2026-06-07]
Machine/SolidWorks/上底板A.SLDPRT
200.0 x 3.00 x 200.0 mm

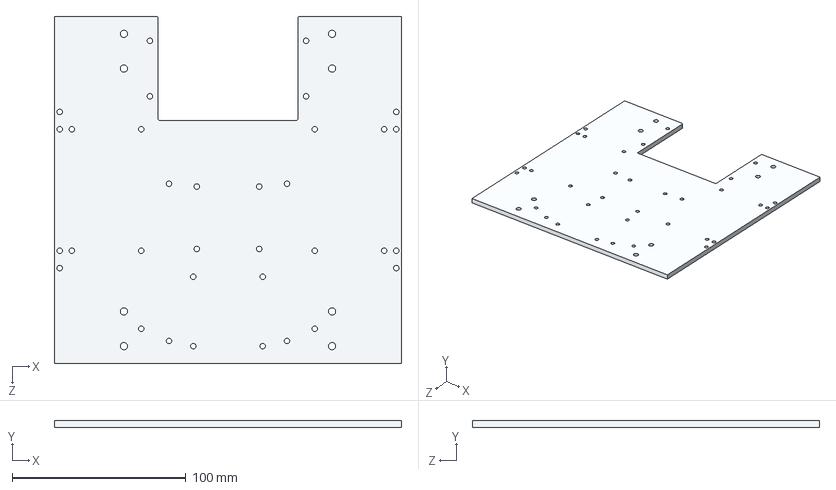
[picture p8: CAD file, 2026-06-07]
Machine/机加工件/CNC/底板.STEP
200.0 x 4.00 x 200.0 mm

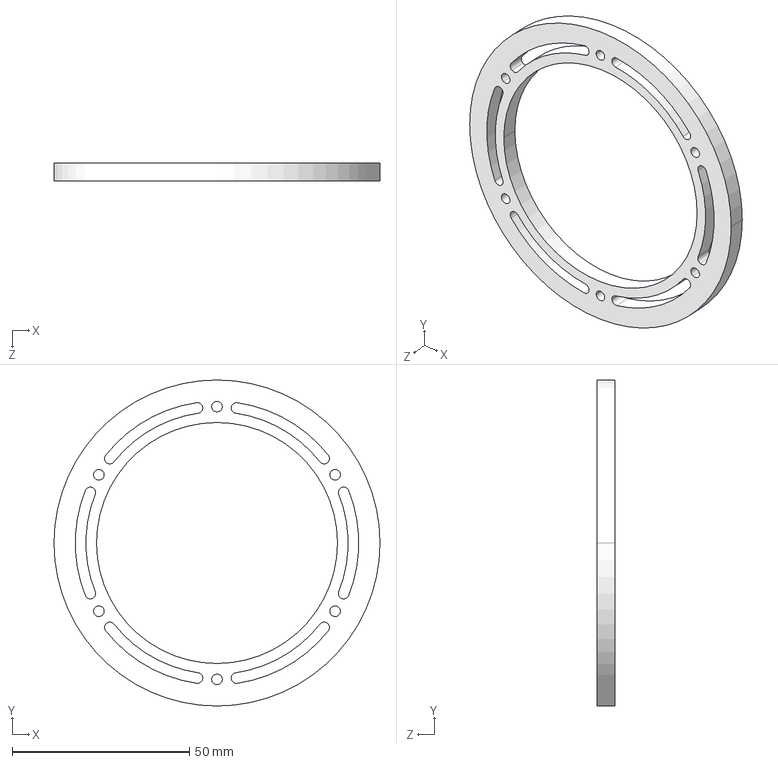
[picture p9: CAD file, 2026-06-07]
Machine/机加工件/玻纤板/轮毂-下盖片.STEP
92.0 x 92.0 x 5.00 mm

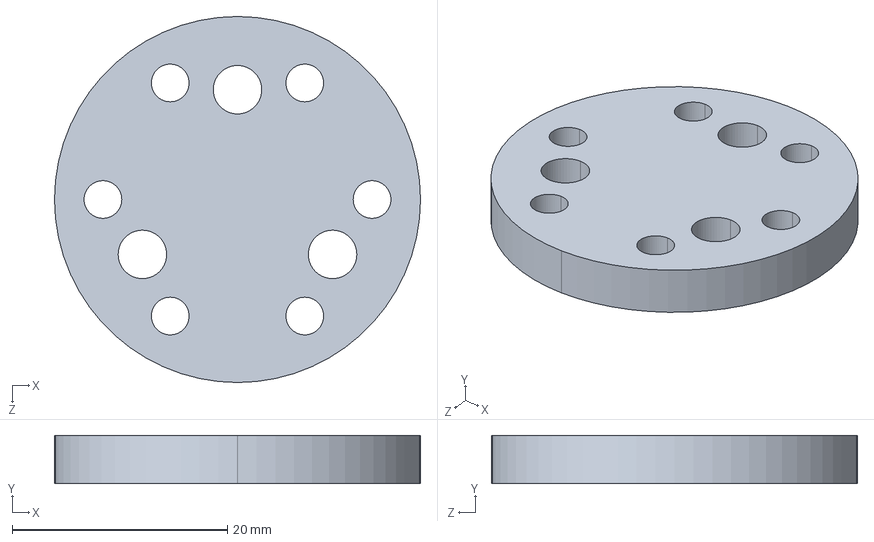
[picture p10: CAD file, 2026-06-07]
Machine/机加工件/CNC/4.5mm垫高片.STEP
34.0 x 4.50 x 34.0 mm

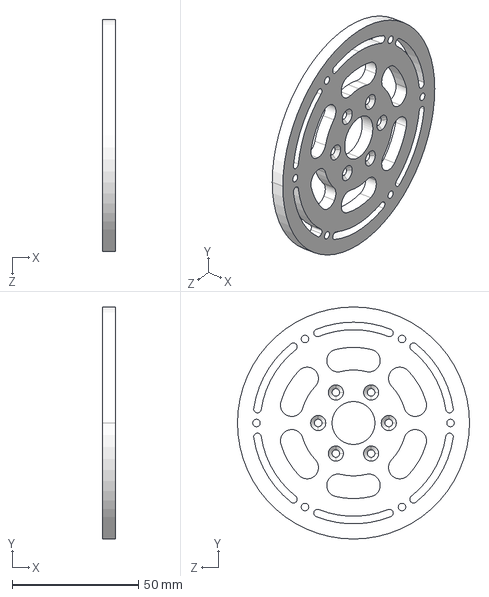
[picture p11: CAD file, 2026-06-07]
Machine/机加工件/玻纤板/轮毂-上盖片.STEP
5.00 x 92.1 x 92.1 mm

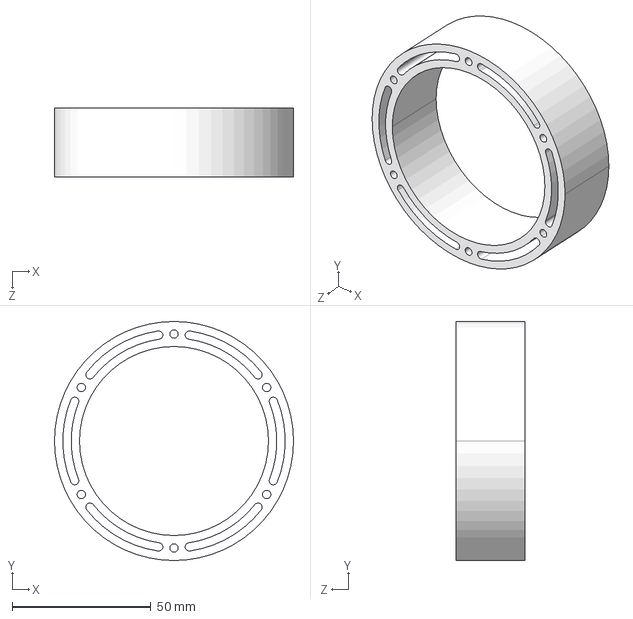
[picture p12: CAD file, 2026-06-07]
Machine/3D打印件/轮毂打印件-内圈.STEP
86.0 x 86.0 x 25.0 mm

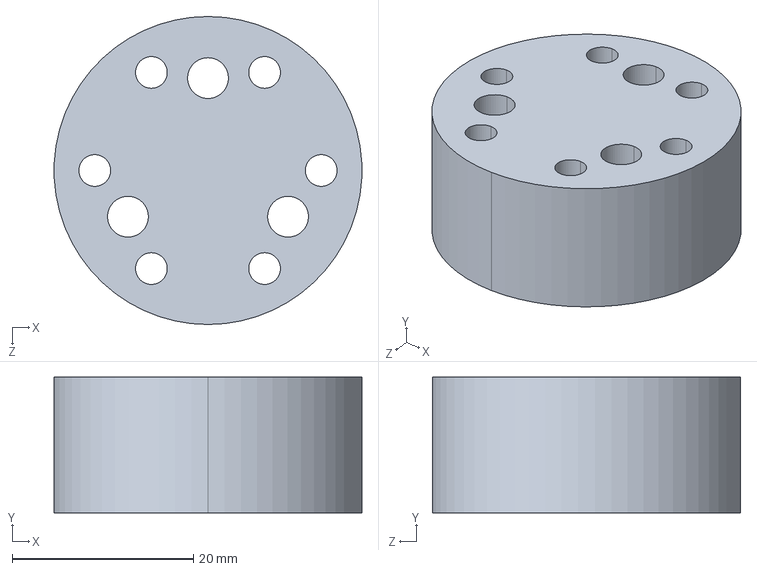
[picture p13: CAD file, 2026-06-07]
Machine/SolidWorks/关节电机支架垫片 第二版(1).STEP
34.0 x 15.0 x 34.0 mm

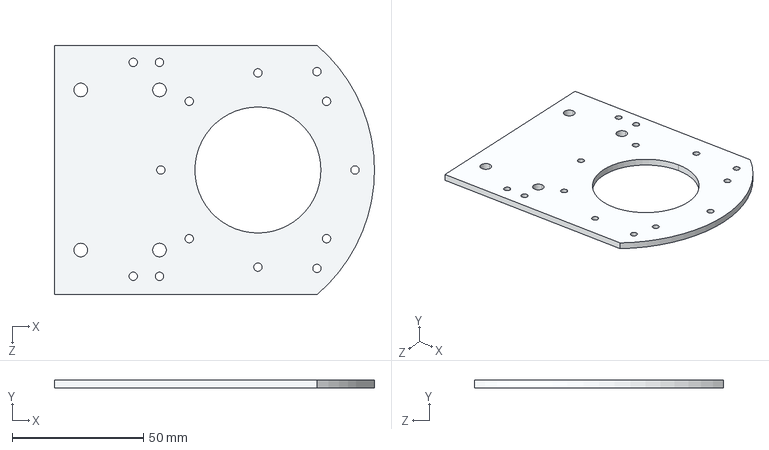
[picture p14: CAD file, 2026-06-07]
Machine/机加工件/CNC/左侧板.STEP
121.9 x 3.00 x 95.0 mm

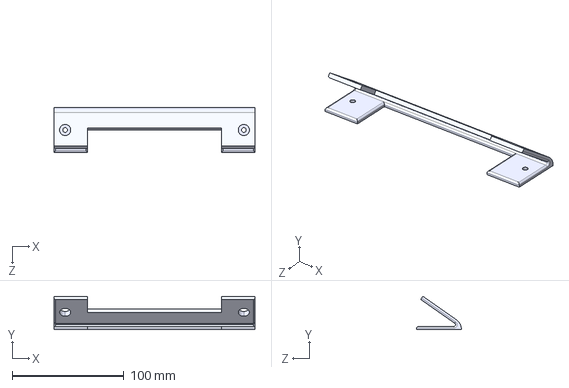
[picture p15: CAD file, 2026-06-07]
Machine/3D打印件/深度相机支架.STEP
180.0 x 29.9 x 40.0 mm

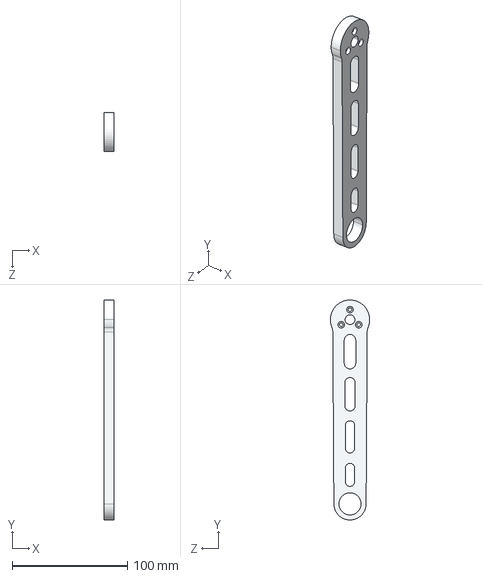
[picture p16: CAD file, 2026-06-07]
Machine/机加工件/CNC/下腿A.STEP
8.50 x 191.1 x 34.2 mm

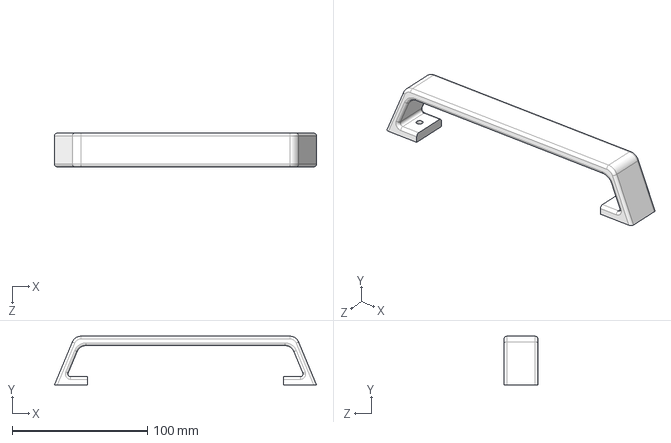
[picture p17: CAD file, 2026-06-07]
Machine/3D打印件/上握把.STEP
194.0 x 36.0 x 25.0 mm

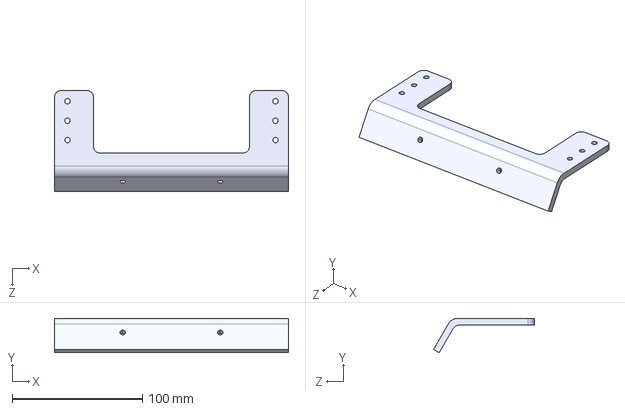
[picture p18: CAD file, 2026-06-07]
Machine/3D打印件/显示屏支架.STEP
180.0 x 26.4 x 77.6 mm

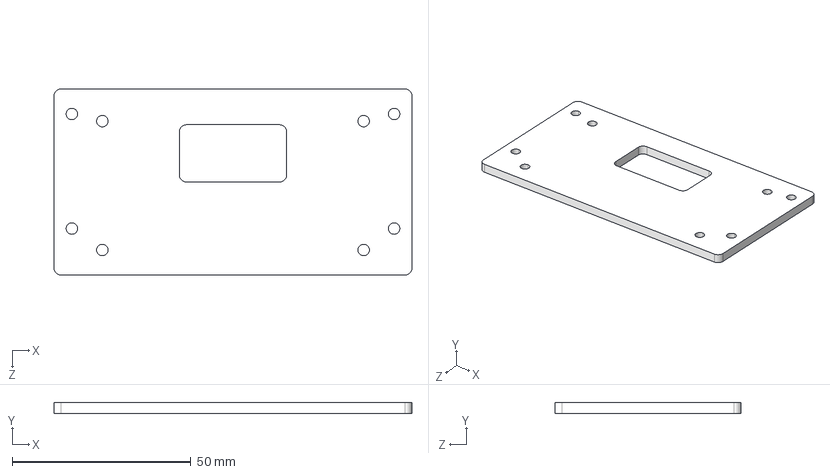
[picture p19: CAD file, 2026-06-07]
Machine/机加工件/CNC/大疆电池转接架.STEP
100.0 x 3.00 x 52.0 mm

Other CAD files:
Machine/SolidWorks/电机-轮.SLDASM
Machine/3D打印件/后挡板.STEP
Machine/SolidWorks/前挡板.SLDPRT
Machine/机加工件/CNC/右侧板.STEP
Machine/3D打印件/LD06雷达转接架.STEP
Machine/SolidWorks/0.5mm垫片.SLDPRT
Machine/SolidWorks/5x2实心轮胎.SLDPRT
Machine/SolidWorks/6010-8安装尺寸图.stp
Machine/SolidWorks/6215_轮毂电机3d模型20230511.SLDPRT
Machine/SolidWorks/7寸显示屏.SLDPRT
Machine/SolidWorks/M10 L20螺钉.SLDPRT
Machine/SolidWorks/M10 L35螺钉.SLDPRT
Machine/SolidWorks/M10法兰轴承.SLDPRT
Machine/SolidWorks/M3-12铜柱.SLDPRT
Machine/SolidWorks/M3-50铜柱.SLDPRT
Machine/SolidWorks/M3-5铜柱.SLDPRT
Machine/SolidWorks/M3长铝条6x6x30.SLDPRT
Machine/SolidWorks/m3螺母.SLDPRT
Machine/SolidWorks/后挡板.SLDPRT
Machine/SolidWorks/大疆电池转接架.SLDPRT
Machine/SolidWorks/左侧板A.SLDPRT
Machine/SolidWorks/底板.SLDPRT
Machine/SolidWorks/显示屏第二版支架.SLDPRT
Machine/SolidWorks/杯头螺丝-m3_40.SLDPRT
Machine/SolidWorks/沉头螺丝-m3_10.SLDPRT
Machine/SolidWorks/深度相机.SLDPRT
Machine/SolidWorks/第二版深度相机支架.SLDPRT
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

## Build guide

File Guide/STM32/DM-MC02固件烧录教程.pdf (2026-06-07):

# DM-MC02 开发板固件烧录教程

使用 Type-C 5V 接口为开发板供电，开发板烧录口连接烧录器(例如 ST-

Link,DAP-Link)

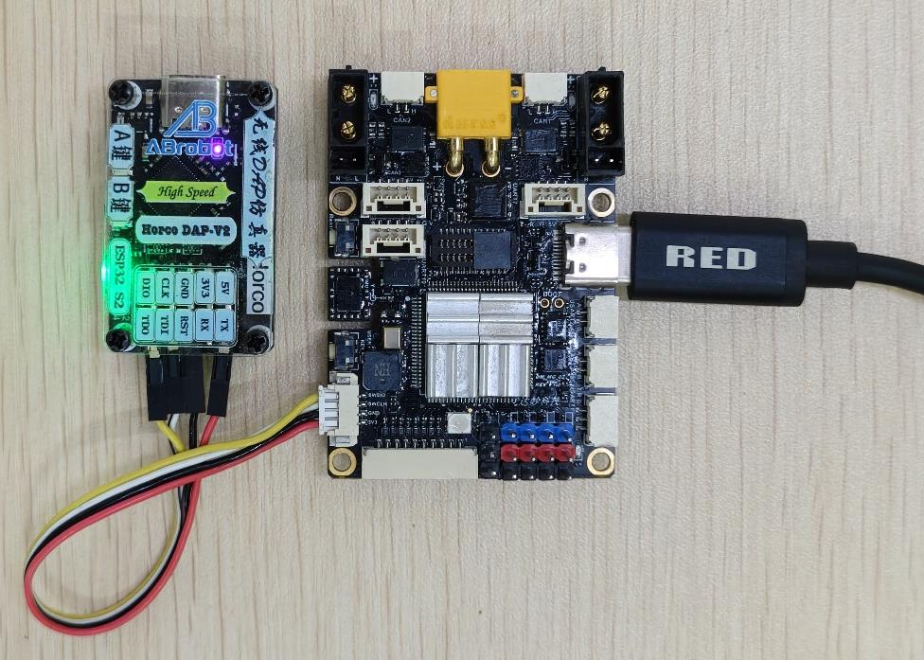
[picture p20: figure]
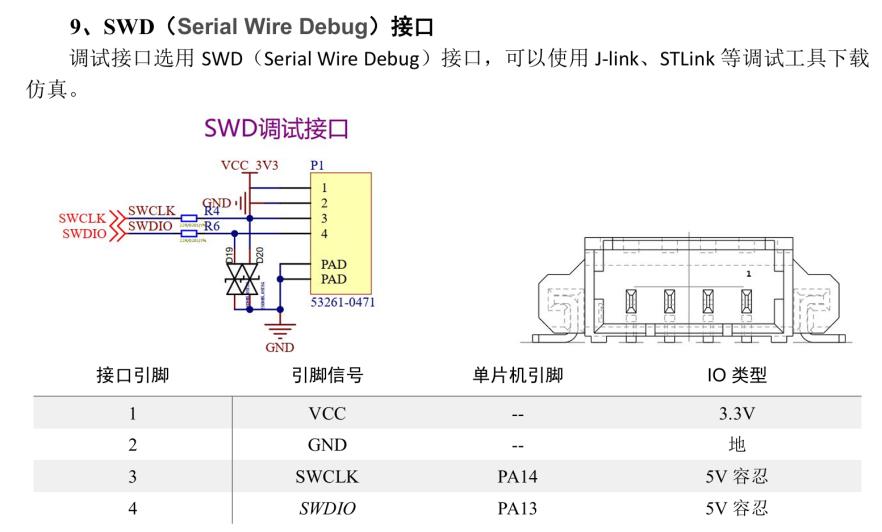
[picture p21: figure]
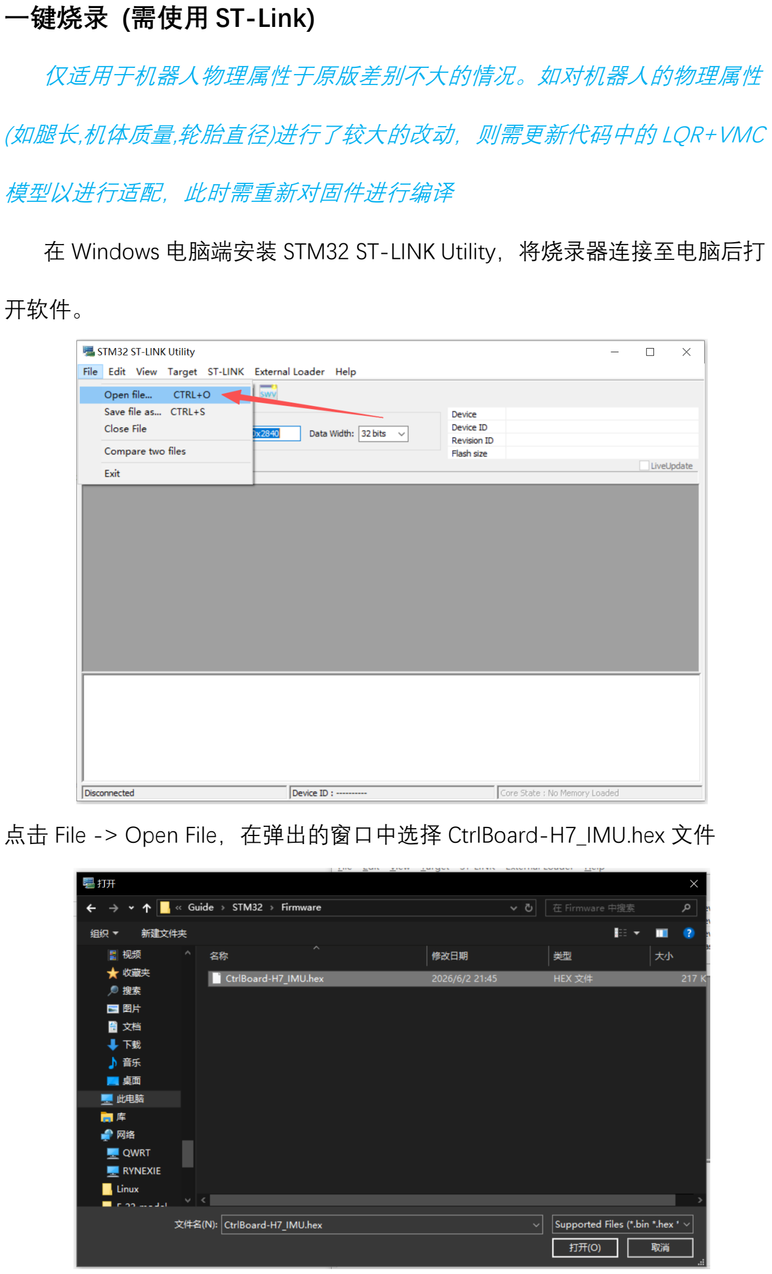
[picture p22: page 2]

一键烧录 (需使用 ST-Link)

仅适用于机器人物理属性于原版差别不大的情况。如对机器人的物理属性

(如腿长,机体质量,轮胎直径)进行了较大的改动，则需更新代码中的 LQR+VMC

模型以进行适配，此时需重新对固件进行编译

在 Windows 电脑端安装 STM32 ST-LINK Utility，将烧录器连接至电脑后打

开软件。

点击 File -> Open File，在弹出的窗口中选择 CtrlBoard-H7_IMU.hex 文件

点击 Program 按钮完成烧录

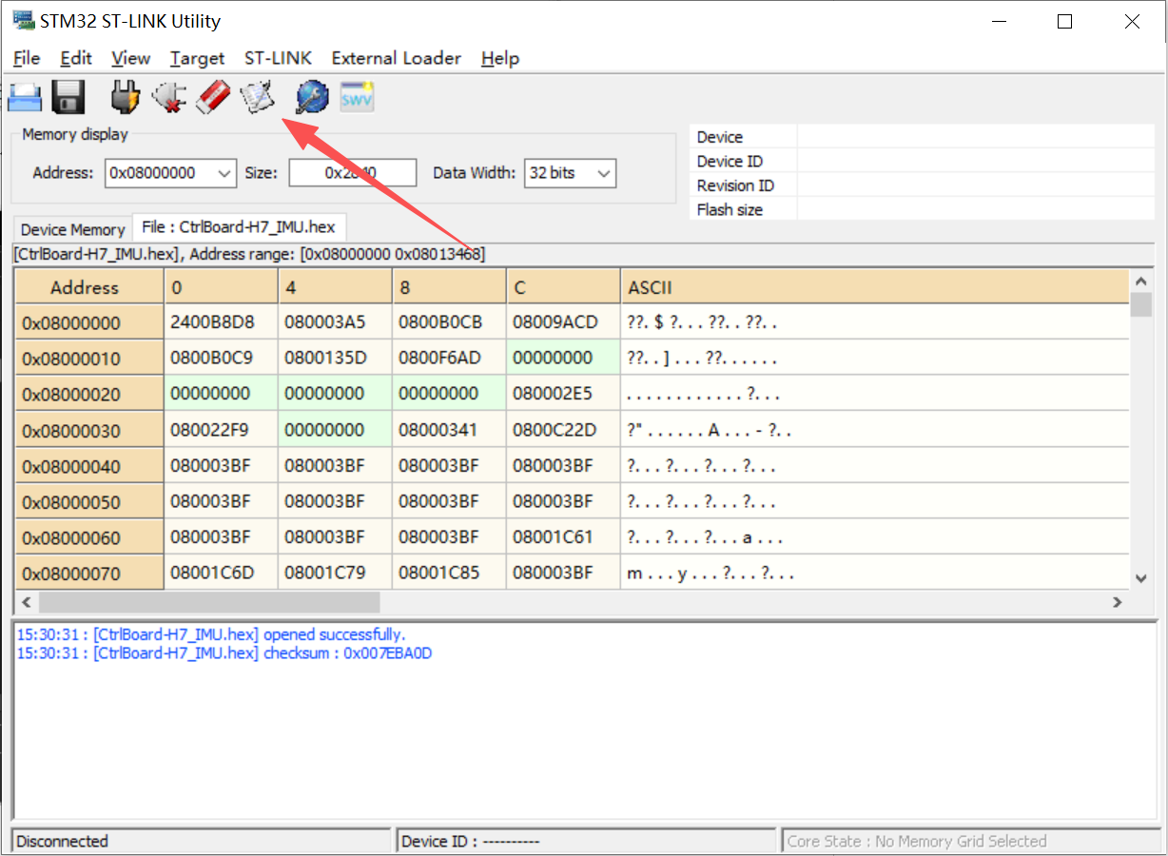
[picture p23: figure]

Keil 编译&烧录

安装 Keil5 后，双击打开项目工程文件

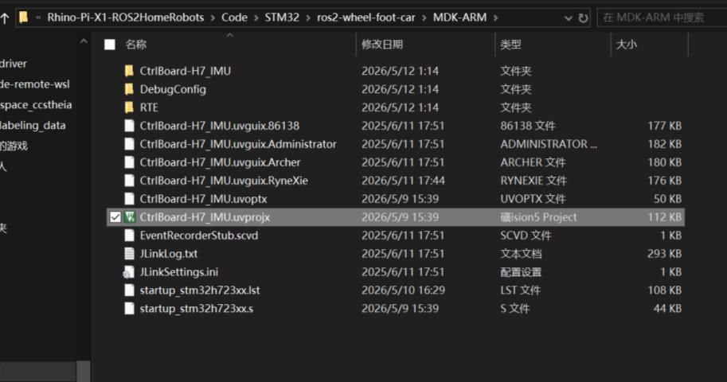
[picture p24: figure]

需要更新的几处参数

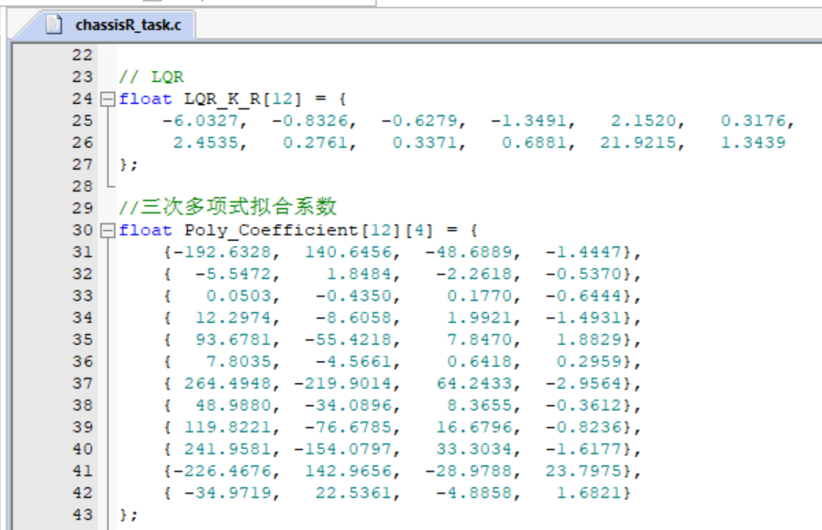
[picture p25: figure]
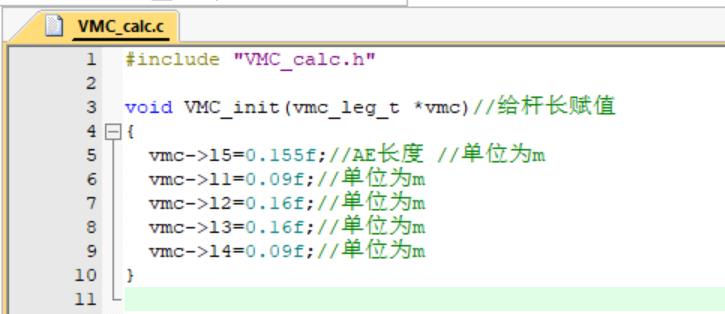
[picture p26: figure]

完成后重新编译固件并进行烧录

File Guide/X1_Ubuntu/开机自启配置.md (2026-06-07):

# 开机自启动配置教程

## 方法一：/etc/aidlux/ 脚本目录

系统已配置 `/etc/rc.local` 在开机时自动遍历执行 `/etc/aidlux/` 下的所有可执行脚本。

### 使用步骤

1. 创建脚本文件（例如 `/etc/aidlux/my-startup.sh`）：

```bash
sudo tee /etc/aidlux/my-startup.sh << 'EOF'
#!/bin/bash
nohup your_command_here > /var/log/my-startup.log 2>&1 &
EOF
```

2. 赋予执行权限：

```bash
sudo chmod 775 /etc/aidlux/my-startup.sh
```

3. 重启验证，或手动测试：

```bash
sudo /etc/aidlux/my-startup.sh
```

### 示例：开机自动启动 aidllm API 服务

```bash
# 创建脚本
sudo tee /etc/aidlux/start-aidllm << 'EOF'
#!/bin/bash
nohup aidllm start api -m Qwen3-4B-Instruct-cl4096 > /var/log/aidllm.log 2>&1 &
EOF

# 赋予执行权限
sudo chmod 775 /etc/aidlux/start-aidllm
```

### 注意事项

- 脚本需要以 `#!/bin/bash` 开头，指定解释器
- 后台运行需使用 `nohup ... &` 或 `&`，否则会阻塞开机流程
- 标准输出和错误输出建议重定向到日志文件，方便排查问题
- 如果脚本需要延迟执行，可在命令前加 `sleep N`

---

## 方法二：systemd 服务（标准方式）

这是 Linux 标准开机自启方案，适用于需要精细控制的守护进程。

### 创建服务文件

创建 `/etc/systemd/system/my-service.service`：

```ini
[Unit]
Description=My Service Description
After=network.target

[Service]
ExecStart=/path/to/your/command
Restart=on-failure
User=root
StandardOutput=append:/var/log/my-service.log
StandardError=append:/var/log/my-service.log

[Install]
WantedBy=multi-user.target
```

### 启用并启动

```bash
sudo systemctl daemon-reload
sudo systemctl enable my-service.service
sudo systemctl start my-service.service
sudo systemctl status my-service.service
```

### 常用管理命令

| 命令 | 说明 |
|---|---|
| `systemctl enable <service>` | 启用开机自启 |
| `systemctl disable <service>` | 禁用开机自启 |
| `systemctl start <service>` | 立即启动 |
| `systemctl stop <service>` | 停止服务 |
| `systemctl status <service>` | 查看状态 |
| `systemctl restart <service>` | 重启服务 |
| `journalctl -u <service>` | 查看日志 |

---

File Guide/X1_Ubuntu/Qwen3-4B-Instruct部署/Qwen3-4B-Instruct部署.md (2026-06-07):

# Qwen3-4B-Instruct 端侧部署指南 — AidGen C++ API + AidGenSE OpenAI API

## 概述

通过MMS拉取Qwen3-4B-Instruct模型，并将模型注册到 AidGenSE，提供标准 OpenAI API

## 环境

| 项目 | 规格 |
|---|---|
| 设备 | Rhino Pi-X1 |
| SoC | Qualcomm QCS8550 |
| 系统 | Ubuntu 22.04 |

## 通过MMS拉取Qwen3-4B-Instruct模型资源

```bash
cd ~
mkdir aidllm && cd aidllm
mkdir Qwen3-4B-Instruct && cd Qwen3-4B-Instruct
mms get -m Qwen3-4B-Instruct-2507 -p w4a16 -c qcs8550 -b qnn2.36 -d qwen3-4b-instruct
unzip qnn236_qcs8550_cl4096.zip
# 模型将被解压到 ~/aidllm/Qwen3-4B-Instruct/qnn236_qcs8550_cl4096/
```

## 导入Tokenizer
MMS的模型包中不包含 tokenizer，需复用 Qwen3-4B (cl2048) 的 `qwen3-4b-tokenizer.json`\
将qwen3-4b-tokenizer.json(位于X1-Pi/Aid_LLM)复制到当前模型目录即可

## 模型目录结构

```
/home/aidlux/aidllm/Qwen3-4B-Instruct/qnn236_qcs8550_cl4096/
├── qwen3-4b-instruct_qnn236_qcs8550_cl4096_1_of_3.aidem   # 模型分片 1/3
├── qwen3-4b-instruct_qnn236_qcs8550_cl4096_2_of_3.aidem   # 模型分片 2/3
├── qwen3-4b-instruct_qnn236_qcs8550_cl4096_3_of_3.aidem   # 模型分片 3/3
├── kv-cache.primary.qnn-htp                                 # KV Cache 配置
├── htp_backend_ext_config.json                              # HTP 后端扩展配置
├── qwen3-4b-tokenizer.json                                  # Tokenizer
└── chat.txt                                                 # 对话模板示例
```

---
将已部署的 cl4096 模型注册到 AidGenSE，提供标准 OpenAI API。
## 安装AidGenSE

```bash
sudo aid-pkg update
sudo aid-pkg -i aidgense
```

## 拷贝模型文件到 AidGenSE 目录

```bash
MODEL_DIR="/opt/aidlux/app/aid-openai-api/res/models/Qwen3-4B-Instruct-cl4096"
mkdir -p "$MODEL_DIR"

SRC="/home/aidlux/aidllm/Qwen3-4B-Instruct/qnn236_qcs8550_cl4096"
cp "$SRC"/qwen3-4b-instruct_qnn236_qcs8550_cl4096_*.aidem "$MODEL_DIR/"
cp "$SRC"/kv-cache.primary.qnn-htp "$MODEL_DIR/"
cp "$SRC"/qwen3-4b-tokenizer.json "$MODEL_DIR/"
cp "$SRC"/htp_backend_ext_config.json "$MODEL_DIR/"
```

### 创建模型配置 JSON

创建 `$MODEL_DIR/Qwen3-4B-Instruct-cl4096.json`：

```json
{
    "backend_type": "genie",
    "prefix_path": "/opt/aidlux/app/aid-openai-api/res/models/Qwen3-4B-Instruct-cl4096/kv-cache.primary.qnn-htp",
    "model": {
        "path": [
            "/opt/aidlux/app/aid-openai-api/res/models/Qwen3-4B-Instruct-cl4096/qwen3-4b-instruct_qnn236_qcs8550_cl4096_1_of_3.aidem",
            "/opt/aidlux/app/aid-openai-api/res/models/Qwen3-4B-Instruct-cl4096/qwen3-4b-instruct_qnn236_qcs8550_cl4096_2_of_3.aidem",
            "/opt/aidlux/app/aid-openai-api/res/models/Qwen3-4B-Instruct-cl4096/qwen3-4b-instruct_qnn236_qcs8550_cl4096_3_of_3.aidem"
        ]
    }
}
```

### 注册到 `api_cfg.json`

编辑 `/opt/aidlux/app/aid-openai-api/api_cfg.json`，在 `model_cfg_list` 中新增：

```json
{
    "model_id": "Qwen3-4B-Instruct-cl4096",
    "model_create": "1774523039284",
    "model_owner": "aplux",
    "cfg_path": "./models/Qwen3-4B-Instruct-cl4096/Qwen3-4B-Instruct-cl4096.json",
    "prompt_template_type": "qwen3"
}
```

`api_cfg.json` 中已有 `qwen3` 的 prompt template，无需重复添加。

### 验证注册

```bash
aidllm list api
```

输出中应包含 `Qwen3-4B-Instruct-cl4096`。

### 启动服务

```bash
aidllm start api -m Qwen3-4B-Instruct-cl4096
```

默认监听 `0.0.0.0:8888`。

### API 测试

**非流式请求**：

```bash
curl http://127.0.0.1:8888/v1/chat/completions \
  -H "Content-Type: application/json" \
  -d '{
    "model": "Qwen3-4B-Instruct-cl4096",
    "messages": [{"role": "user", "content": "中国的首都是哪里？"}]
  }'
```

**流式请求**：

```bash
curl http://127.0.0.1:8888/v1/chat/completions \
  -H "Content-Type: application/json" \
  -d '{
    "model": "Qwen3-4B-Instruct-cl4096",
    "messages": [{"role": "user", "content": "介绍一下LLM"}],
    "stream": true
  }'
```

### 服务管理

```bash
aidllm status api      # 查看运行状态
aidllm stop api        # 停止服务
aidllm restart api     # 重启服务
```

## 模型服务开机自启动
系统已配置 `/etc/rc.local` 在开机时自动遍历执行 `/etc/aidlux/` 下的所有可执行脚本。

### 创建启动脚本（`/etc/aidlux/qwen-llm.sh`）

```bash
sudo tee /etc/aidlux/qwen-llm.sh << 'EOF'
#!/bin/bash
nohup aidllm start api -m Qwen3-4B-Instruct-cl4096 > /var/log/aidllm.log 2>&1 &
EOF
```

### 赋予执行权限

```bash
sudo chmod 775 /etc/aidlux/qwen-llm.sh
```

### 重启验证

```bash
sudo reboot
```
重启后，使用 `aidllm status api` 验证服务是否已自动启动。

---

## 注意事项

| 问题 | 说明 |
|---|---|
| Tokenizer | 模型包中不包含 tokenizer，需复用 Qwen3-4B (cl2048) 的 `qwen3-4b-tokenizer.json`（Qwen3 系列通用） |
| 路径 | AidGenSE 的 config JSON 中需使用**绝对路径** |
| prompt 模板 | Qwen3 模板已内置于 `api_cfg.json` 的 `prompt_template_list` 中 |
| 推理参数 | 可通过 `aidllm start api` 的参数调整设备类型 (`--device`) 等 |

### 推理性能参考

| 指标 | 值 |
|---|:----:|
| Init 耗时 | ~7.85s |
| 首 Token 延迟 (TTFT) | ~118.8ms |
| Prefill 速率 | ~328.3 tok/s |
| Decode 速率 | ~18.6 tok/s |

---

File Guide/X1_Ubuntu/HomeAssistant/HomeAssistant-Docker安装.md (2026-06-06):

# Home Assistant on Docker 部署教程

> Ubuntu 22.04 (ARM64) + Docker + Home Assistant + HACS

---

## 环境信息

- **系统**: Ubuntu 22.04.5 LTS (Jammy)
- **架构**: ARM64 (aarch64)
- **Home Assistant 版本**: 2026.5 (stable)
- **HACS 版本**: 2026.5.4

---

## 一、安装 Docker

### 1.1 安装前置依赖

```bash
sudo apt-get update -qq
sudo apt-get install -y ca-certificates curl gnupg
```

### 1.2 添加国内镜像源

```bash
# 创建密钥目录
sudo install -m 0755 -d /etc/apt/keyrings

# 下载并添加 Docker GPG 密钥（阿里云源）
curl -fsSL https://mirrors.aliyun.com/docker-ce/linux/ubuntu/gpg -o /tmp/docker.gpg
sudo gpg --dearmor --batch --yes -o /etc/apt/keyrings/docker.gpg /tmp/docker.gpg
sudo chmod a+r /etc/apt/keyrings/docker.gpg

# 添加 Docker apt 仓库（阿里云源）
echo "deb [arch=$(dpkg --print-architecture) signed-by=/etc/apt/keyrings/docker.gpg] https://mirrors.aliyun.com/docker-ce/linux/ubuntu jammy stable" | sudo tee /etc/apt/sources.list.d/docker.list
```

### 1.3 安装 Docker

```bash
sudo apt-get update -qq
sudo apt-get install -y docker-ce docker-ce-cli containerd.io docker-buildx-plugin docker-compose-plugin
```

### 1.4 配置镜像加速器

```bash
sudo mkdir -p /etc/docker
sudo tee /etc/docker/daemon.json <<'EOF'
{
  "registry-mirrors": [
    "https://docker.m.daocloud.io",
    "https://dockercf.jmirror.top",
    "https://dockerproxy.com"
  ]
}
EOF
sudo systemctl restart docker
```

### 1.5 验证

```bash
sudo docker run --rm hello-world
```

---

## 二、部署 Home Assistant

### 2.1 创建数据目录

```bash
mkdir -p ~/homeassistant
```

### 2.2 启动容器

```bash
sudo docker run -d \
  --name homeassistant \
  --restart unless-stopped \
  --privileged \
  --network host \
  -v ~/homeassistant:/config \
  -v /run/dbus:/run/dbus:ro \
  -e TZ=Asia/Shanghai \
  homeassistant/home-assistant:stable
```

**参数说明**:

| 参数 | 说明 |
|---|---|
| `-d` | 后台运行 |
| `--name homeassistant` | 容器名称 |
| `--restart unless-stopped` | 开机自启，异常自动重启 |
| `--privileged` | 授予特权，支持访问硬件 |
| `--network host` | 宿主机网络，支持设备发现 |
| `-v ~/homeassistant:/config` | 配置文件持久化 |
| `-v /run/dbus:/run/dbus:ro` | 蓝牙等设备通信 |
| `-e TZ=Asia/Shanghai` | 时区 |

### 2.3 访问

浏览器打开 `http://<本机IP>:8123`，按向导完成初始化。

---

## 三、安装 HACS

### 3.1 下载并安装

```bash
sudo docker exec homeassistant bash -c "wget -O - https://get.hacs.xyz | bash -"
```

### 3.2 重启容器

```bash
sudo docker restart homeassistant
```

### 3.3 激活 HACS

1. 等待 1-2 分钟，刷新 Home Assistant 页面
2. 进入 **设置 → 设备与服务 → 添加集成**
3. 搜索 `HACS` 并添加
4. 按提示授权 GitHub 账号
5. 刷新页面后，左侧菜单栏出现 **HACS**

---

## 四、日常管理

### 容器操作

```bash
# 启动
sudo docker start homeassistant

# 停止
sudo docker stop homeassistant

# 重启
sudo docker restart homeassistant

# 查看状态
sudo docker ps --filter name=homeassistant

# 查看日志（实时）
sudo docker logs -f homeassistant

# 进入容器 Shell
sudo docker exec -it homeassistant bash
```

### 升级 Home Assistant

```bash
# 拉取最新镜像
sudo docker pull homeassistant/home-assistant:stable

# 重建容器（保留 /config 数据）
sudo docker stop homeassistant
sudo docker rm homeassistant
sudo docker run -d \
  --name homeassistant \
  --restart unless-stopped \
  --privileged \
  --network host \
  -v ~/homeassistant:/config \
  -v /run/dbus:/run/dbus:ro \
  -e TZ=Asia/Shanghai \
  homeassistant/home-assistant:stable
```

> 配置文件保存在 `~/homeassistant` 目录，不会因重建容器而丢失。

### 配置文件位置

```
~/homeassistant/
├── configuration.yaml      # 主配置文件
├── automations.yaml        # 自动化
├── scripts.yaml            # 脚本
├── scenes.yaml             # 场景
├── custom_components/      # 自定义组件（含 HACS）
├── hacs                    # HACS 下载的集成/卡片
├── .storage/               # 内部状态存储
└── home-assistant.log      # 运行日志
```

---

## 五、与宿主机通信

Home Assistant 使用 `--network host` 模式，容器内可通过 `127.0.0.1` 直接访问宿主机上运行的任何服务。

例如宿主机上 8888 端口有服务，在 HA 配置中直接使用：

```yaml
rest_command:
  local_service:
    url: "http://127.0.0.1:8888/api"
    method: POST
```

---

## 六、备份与恢复

### 备份

```bash
# 停止容器
sudo docker stop homeassistant

# 打包配置文件
tar -czf ha-backup-$(date +%Y%m%d).tar.gz ~/homeassistant

# 重启容器
sudo docker start homeassistant
```

### 恢复

```bash
# 停止容器
sudo docker stop homeassistant

# 恢复配置
tar -xzf ha-backup-YYYYMMDD.tar.gz -C /

# 重启容器
sudo docker start homeassistant
```

---

## 七、常见问题

### 镜像拉取失败

更换 `daemon.json` 中的镜像加速器地址，然后重启 Docker：

```bash
sudo systemctl restart docker
```

### 容器异常退出

查看日志定位问题：

```bash
sudo docker logs --tail 100 homeassistant
```

常见原因：`configuration.yaml` 语法错误 → 检查缩进和格式。

### 端口被占用

检查 8123 端口：

```bash
sudo lsof -i :8123
```

### 无法访问宿主机服务

确认容器使用了 `--network host`：

```bash
sudo docker inspect homeassistant | grep NetworkMode
```

输出应为 `"NetworkMode": "host"`。

---

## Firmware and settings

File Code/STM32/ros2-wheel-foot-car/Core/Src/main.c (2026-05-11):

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
/* Includes ------------------------------------------------------------------*/
#include "main.h"
#include "cmsis_os.h"
#include "adc.h"
#include "dma.h"
#include "fdcan.h"
#include "spi.h"
#include "tim.h"
#include "usart.h"
#include "usb_device.h"
#include "gpio.h"

/* USER CODE BEGIN Includes */
#include "BMI088driver.h"
#include "kalman_filter.h"
#include "mahony_filter.h"
#include "bsp_dwt.h"
#include "BMI088Middleware.h"
#include "can_bsp.h"
#include "vofa_task.h"
/* USER CODE END Includes */


void SystemClock_Config(void);
void PeriphCommonClock_Config(void);
static void MPU_Config(void);
void MX_FREERTOS_Init(void);
/* USER CODE BEGIN PFP */
extern volatile uint8_t rx_data_byte;
/* USER CODE END PFP */

/**
  * @brief  The application entry point.
  * @retval int
  */
int main(void)
{

  /* MPU Configuration--------------------------------------------------------*/
  MPU_Config();

  /* Enable the CPU Cache */

  /* Enable I-Cache---------------------------------------------------------*/
  SCB_EnableICache();

  /* Enable D-Cache---------------------------------------------------------*/
  SCB_EnableDCache();

  /* MCU Configuration--------------------------------------------------------*/

  /* Reset of all peripherals, Initializes the Flash interface and the Systick. */
  HAL_Init();

  /* USER CODE BEGIN Init */
//06 01 00 00 00 00 00 00 00 00 00 00 00 00 80 3F
  /* USER CODE END Init */

  /* Configure the system clock */
  SystemClock_Config();

  /* Configure the peripherals common clocks */
  PeriphCommonClock_Config();

  /* Initialize all configured peripherals */
  MX_GPIO_Init();
  MX_DMA_Init();
  MX_SPI2_Init();
  MX_FDCAN1_Init();
  MX_FDCAN2_Init();
  MX_TIM3_Init();
  MX_FDCAN3_Init();
  MX_UART7_Init();
  MX_ADC1_Init();
  MX_TIM12_Init();
  MX_USART1_UART_Init();
  MX_USART10_UART_Init();
  /* USER CODE BEGIN 2 */
  MX_USB_DEVICE_Init();
  
  HAL_UART_Receive_IT(&huart7, &rx_data_byte, 1);

	DWT_Init(480);
  
    /* BMI088初始化 */
  while (BMI088_init(&hspi2, 0) != BMI088_NO_ERROR)
	{
	  ;
	}
	Power_OUT1_OFF;//imu初始化完成，可控电源打开，led灯亮
	Power_OUT2_OFF;
	
  FDCAN1_Config();//can过滤器初始化
	FDCAN2_Config();

  /* USER CODE END 2 */

  /* Call init function for freertos objects (in cmsis_os2.c) */
  MX_FREERTOS_Init();

  /* Start scheduler */
  osKernelStart();

  /* We should never get here as control is now taken by the scheduler */

  /* Infinite loop */
  /* USER CODE BEGIN WHILE */
  while (1)
  {
    /* USER CODE END WHILE */

    /* USER CODE BEGIN 3 */
 
  }
  /* USER CODE END 3 */
}

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
/* USER CODE BEGIN 4 */

// void HAL_UART_RxCpltCallback(UART_HandleTypeDef *huart){
//     UART_PrintString(&huart10, "UART Rx Complete\r\n");
//     HAL_UART_Receive_IT(&huart7, &rx_data_buff, sizeof(rx_data_buff));
// }
/* USER CODE END 4 */

 /* MPU Configuration */

void MPU_Config(void)
{
  MPU_Region_InitTypeDef MPU_InitStruct = {0};

  /* Disables the MPU */
  HAL_MPU_Disable();

  /** Initializes and configures the Region and the memory to be protected
  */
  MPU_InitStruct.Enable = MPU_REGION_ENABLE;
  MPU_InitStruct.Number = MPU_REGION_NUMBER0;
  MPU_InitStruct.BaseAddress = 0x0;
  MPU_InitStruct.Size = MPU_REGION_SIZE_4GB;
  MPU_InitStruct.SubRegionDisable = 0x87;
  MPU_InitStruct.TypeExtField = MPU_TEX_LEVEL0;
  MPU_InitStruct.AccessPermission = MPU_REGION_NO_ACCESS;
  MPU_InitStruct.DisableExec = MPU_INSTRUCTION_ACCESS_DISABLE;
  MPU_InitStruct.IsShareable = MPU_ACCESS_SHAREABLE;
  MPU_InitStruct.IsCacheable = MPU_ACCESS_NOT_CACHEABLE;
  MPU_InitStruct.IsBufferable = MPU_ACCESS_NOT_BUFFERABLE;

  HAL_MPU_ConfigRegion(&MPU_InitStruct);
  /* Enables the MPU */
  HAL_MPU_Enable(MPU_PRIVILEGED_DEFAULT);

}

/**
  * @brief  Period elapsed callback in non blocking mode
  * @note   This function is called  when TIM2 interrupt took place, inside
  * HAL_TIM_IRQHandler(). It makes a direct call to HAL_IncTick() to increment
  * a global variable "uwTick" used as application time base.
  * @param  htim : TIM handle
  * @retval None
  */
void HAL_TIM_PeriodElapsedCallback(TIM_HandleTypeDef *htim)
{
  if (htim->Instance == TIM2)
  {
    HAL_IncTick();
  }
}

/**
  * @brief  This function is executed in case of error occurrence.
  * @retval None
  */
void Error_Handler(void)
{
  /* USER CODE BEGIN Error_Handler_Debug */
  /* User can add his own implementation to report the HAL error return state */
  __disable_irq();
  while (1)
  {
  }
  /* USER CODE END Error_Handler_Debug */
}
#ifdef USE_FULL_ASSERT
/**
  * @brief  Reports the name of the source file and the source line number
  *         where the assert_param error has occurred.
  * @param  file: pointer to the source file name
  * @param  line: assert_param error line source number
  * @retval None
  */
void assert_failed(uint8_t *file, uint32_t line)
{
  /* USER CODE BEGIN 6 */
  /* User can add his own implementation to report the file name and line number,
     ex: printf("Wrong parameters value: file %s on line %d\r\n", file, line) */
  /* USER CODE END 6 */
}
#endif /* USE_FULL_ASSERT */

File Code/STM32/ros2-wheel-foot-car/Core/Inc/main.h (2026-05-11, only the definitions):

#define DC24_1__OUTPUT_Pin GPIO_PIN_13
#define DC24_1__OUTPUT_GPIO_Port GPIOC
#define DC24_0__OUTPUT_Pin GPIO_PIN_14
#define DC24_0__OUTPUT_GPIO_Port GPIOC
#define DC5__OUTPUT_Pin GPIO_PIN_15
#define DC5__OUTPUT_GPIO_Port GPIOC
#define ACC_CS_Pin GPIO_PIN_0
#define ACC_CS_GPIO_Port GPIOC
#define GYRO_CS_Pin GPIO_PIN_3
#define GYRO_CS_GPIO_Port GPIOC
#define DI_Pin GPIO_PIN_0
#define DI_GPIO_Port GPIOA
#define DO_Pin GPIO_PIN_2
#define DO_GPIO_Port GPIOA
#define BAT_VOLTAGE__ADC_Pin GPIO_PIN_4
#define BAT_VOLTAGE__ADC_GPIO_Port GPIOC
#define CS_Pin GPIO_PIN_9
#define CS_GPIO_Port GPIOE
#define ACC_INT_Pin GPIO_PIN_10
#define ACC_INT_GPIO_Port GPIOE
#define GYRO_INT_Pin GPIO_PIN_12
#define GYRO_INT_GPIO_Port GPIOE
#define CLK_Pin GPIO_PIN_13
#define CLK_GPIO_Port GPIOE
#define BEEP_Pin GPIO_PIN_15
#define BEEP_GPIO_Port GPIOB

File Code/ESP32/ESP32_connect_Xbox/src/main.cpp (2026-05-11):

#include <Arduino.h>
#include <XboxSeriesXControllerESP32_asukiaaa.hpp>

// Required to replace with your xbox address
// 需要在此替换成自己的手柄蓝牙MAC地址
XboxSeriesXControllerESP32_asukiaaa::Core
    xboxController("58:d0:05:0e:85:8d");

String xbox_string()
{
  String str = String(xboxController.xboxNotif.btnY) + "," +
               String(xboxController.xboxNotif.btnX) + "," +
               String(xboxController.xboxNotif.btnB) + "," +
               String(xboxController.xboxNotif.btnA) + "," +
               String(xboxController.xboxNotif.btnLB) + "," +
               String(xboxController.xboxNotif.btnRB) + "," +
               String(xboxController.xboxNotif.btnSelect) + "," +
               String(xboxController.xboxNotif.btnStart) + "," +
               String(xboxController.xboxNotif.btnXbox) + "," +
               String(xboxController.xboxNotif.btnShare) + "," +
               String(xboxController.xboxNotif.btnLS) + "," +
               String(xboxController.xboxNotif.btnRS) + "," +
               String(xboxController.xboxNotif.btnDirUp) + "," +
               String(xboxController.xboxNotif.btnDirRight) + "," +
               String(xboxController.xboxNotif.btnDirDown) + "," +
               String(xboxController.xboxNotif.btnDirLeft) + "," +
               String(xboxController.xboxNotif.joyLHori) + "," +
               String(xboxController.xboxNotif.joyLVert) + "," +
               String(xboxController.xboxNotif.joyRHori) + "," +
               String(xboxController.xboxNotif.joyRVert) + "," +
               String(xboxController.xboxNotif.trigLT) + "," +
               String(xboxController.xboxNotif.trigRT) + "\n";
  return str;
};

void xbox_string_format(uint8_t *data)
{
  bool btnA = xboxController.xboxNotif.btnA;
  bool btnB = xboxController.xboxNotif.btnB;
  bool btnX = xboxController.xboxNotif.btnX;
  bool btnY = xboxController.xboxNotif.btnY;
  bool btnLB = xboxController.xboxNotif.btnLB;
  bool btnRB = xboxController.xboxNotif.btnRB;
  bool btnXbox = xboxController.xboxNotif.btnXbox;

  // 获取摇杆和扳机的值，中心为0
  // -100 - 100范围内 向上为正 向右为正
  int joyL_X = (int)(((float)xboxController.xboxNotif.joyLHori - 32768.0) / 32768.0 * 100.0);
  int joyL_Y = -(int)(((float)xboxController.xboxNotif.joyLVert - 32768.0) / 32768.0 * 100.0);
  int joyR_X = (int)(((float)xboxController.xboxNotif.joyRHori - 32768.0) / 32768.0 * 100.0);
  int joyR_Y = -(int)(((float)xboxController.xboxNotif.joyRVert - 32768.0) / 32768.0 * 100.0);
  int trig_L = (int)(((float)xboxController.xboxNotif.trigLT) / 1023.0 * 100.0);
  int trig_R = (int)(((float)xboxController.xboxNotif.trigRT) / 1023.0 * 100.0);

  //包头
  uint8_t header[2] = {0x07, 0x21};

  data[0] = header[0];
  data[1] = header[1];
  data[2] = (uint8_t)(joyL_X) + 128;
  data[3] = (uint8_t)(joyL_Y) + 128;
  data[4] = (uint8_t)(joyR_X) + 128;
  data[5] = (uint8_t)(joyR_Y) + 128;
  data[6] = (uint8_t)(trig_L);
  data[7] = (uint8_t)(trig_R);
  data[8] = (btnA << 0) | (btnLB << 1) | (btnRB << 2) | (btnXbox << 3);
  data[9] = (btnB << 0) | (btnX << 1) | (btnY << 2);
  // 校验和：对前10个字节求和后取低8位
  uint16_t checksum = 0;
  for (int i = 0; i < 10; ++i)
  {
    checksum += data[i];
  }
  data[10] = (uint8_t)(checksum & 0xFF);
}

void uart_feedback()
{
  uint8_t data[11];
  xbox_string_format(data);
  Serial1.write(data, sizeof(data));
}

// Serial1 接收帧解析：检测包头 0x07 0x21 时触发振动
static uint8_t rxState = 0;
static unsigned long vibrationTriggeredAt = 0;
static const unsigned long vibrationCooldownMs = 300;

void triggerVibration()
{
  unsigned long now = millis();
  if (now - vibrationTriggeredAt < vibrationCooldownMs) return;
  vibrationTriggeredAt = now;

  XboxSeriesXHIDReportBuilder_asukiaaa::ReportBase repo;
  repo.setAllOff();
  repo.v.select.shake = true;
  repo.v.select.center = true;
  repo.v.power.shake = 50;
  repo.v.power.center = 50;
  repo.v.timeActive = 25;   // 250ms
  repo.v.timeSilent = 0;
  repo.v.countRepeat = 0;
  xboxController.writeHIDReport(repo);
}

void serial1_onReceive()
{
  while (Serial1.available()) {
    uint8_t byte = Serial1.read();
    if (rxState == 0 && byte == 0x07) {
      rxState = 1;
    } else if (rxState == 1 && byte == 0x21) {
      rxState = 0;
      triggerVibration();
    } else {
      rxState = 0;
    }
  }
}

/*
支持四种振动模式
left：上左电机动
right：上右电机动
center：下左电机和下右电机一起动，频率高力量小
shake：下左电机和下右电机一起动，频率低力量大

测试结果：
四种模式都可以调振动力度
下左电机和下右电机是绑定的，只能一起动，但是提供了两种振动模式，个人猜测是两种模式的原理是给电机不同的电压
可以随意搭配使用，但center和shake一起用的话执行的应该是shake
*/

// 配置参考
// repo.v.select.center = 0;
// repo.v.select.left = 0;
// repo.v.select.right = 0;
// repo.v.select.shake = 0;
// repo.v.power.center = 0; // x% power
// repo.v.power.left = 0;
// repo.v.power.right = 30;
// repo.v.power.shake = 0;
// repo.v.timeActive = 0; // 振动 x/100 秒，最大2.56秒(uint8_t)
// repo.v.timeSilent = 0;   // 静止 x/100 秒
// repo.v.countRepeat = 0;  // 循环次数 x+1

// 官方例程
void demoVibration()
{
  XboxSeriesXHIDReportBuilder_asukiaaa::ReportBase repo;
  Serial.println("full power for 1 sec");
  xboxController.writeHIDReport(repo);
  delay(2000);

  repo.v.select.center = true;
  repo.v.select.left = false;
  repo.v.select.right = false;
  repo.v.select.shake = false;
  repo.v.power.center = 30; // 30% power
  Serial.println("run center 30\% power in half second");
  xboxController.writeHIDReport(repo);
  delay(2000);

  repo.v.select.center = false;
  repo.v.select.left = true;
  repo.v.power.left = 30;
  Serial.println("run left 30\% power in half second");
  xboxController.writeHIDReport(repo);
  delay(2000);

  repo.v.select.left = false;
  repo.v.select.right = true;
  repo.v.power.right = 30;
  Serial.println("run right 30\% power in half second");
  xboxController.writeHIDReport(repo);
  delay(2000);

  repo.v.select.right = false;
  repo.v.select.shake = true;
  repo.v.power.shake = 30;
  Serial.println("run shake 30\% power in half second");
  xboxController.writeHIDReport(repo);
  delay(2000);

  repo.v.select.shake = false;
  repo.v.select.center = true;
  repo.v.power.center = 50;
  repo.v.timeActive = 20;
  repo.v.timeSilent = 20;
  repo.v.countRepeat = 2;
  Serial.println("run center 50\% power in 0.2 sec 3 times");
  xboxController.writeHIDReport(repo);
  delay(2000);
}

// 振动反馈，根据扳机按压力度调整振动力度
void demoVibration_2()
{
  XboxSeriesXHIDReportBuilder_asukiaaa::ReportBase repo;
  static uint16_t TrigMax = XboxControllerNotificationParser::maxTrig;
  String str_1;
  repo.setAllOff();
  repo.v.select.left = true;
  repo.v.select.right = true;
  repo.v.power.left = (uint8_t)((float)xboxController.xboxNotif.trigLT / (float)TrigMax * 100);
  repo.v.power.right = (uint8_t)((float)xboxController.xboxNotif.trigRT / (float)TrigMax * 100);
  repo.v.timeActive = 50;
  xboxController.writeHIDReport(repo);
  str_1 = String(repo.v.power.left) + "," + String(repo.v.power.right) + "\n";

  Serial.print(str_1);
  delay(50);
}
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

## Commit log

2026-05-11 加入PCB文件
2026-05-13 更新ROS2接口层和控制层代码
2026-05-13 更新README
2026-05-27 更新Matlab仿真文件
2026-06-05 更新硬件安装指南
2026-06-06 更新X1-Pi和STM32 README文档
    X1-Pi README:
    - 补充系统架构图
    - 修正 Voice_Assistant → HA_VoiceAssistant
    - 新增 emotion_display 模块说明
    - 添加各模块详细功能点和硬件依赖表
    STM32 README:
    - 补充硬件平台表（MCU/IMU/电机型号）
    - 展开完整目录树及各文件用途
    - 添加 FreeRTOS 任务系统表
    - 补充控制架构图和控制输入说明
    - 添加调试(VOFA+)/电源管理子模块文档链接
2026-06-06 添加表情显示动画和语音助手包
2026-06-06 更新相关手册
2026-06-06 添加 Home Assistant 和 Qwen3-4B-Instruct 部署指南文档，包含 Docker 安装和开机自启配置
2026-06-07 更新STM32固件烧录教程
2026-06-07 添加语音助手相关文档
2026-06-07 更新ROS2层
2026-06-07 更新机械文件和相关README
    [0.5mm垫片.SLDPRT, 15mm垫高片.STEP, 4.5mm垫高片.STEP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]
2026-06-07 更新物料清单
    [物料清单-机械.xlsx]
2026-06-08 更新电子部分的物料清单
    [物料清单-电子.xlsx]
2026-06-08 安装指南更新至1.1版

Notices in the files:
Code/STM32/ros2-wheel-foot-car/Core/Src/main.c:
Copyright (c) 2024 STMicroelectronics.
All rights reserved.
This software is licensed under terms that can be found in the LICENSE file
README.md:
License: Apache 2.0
